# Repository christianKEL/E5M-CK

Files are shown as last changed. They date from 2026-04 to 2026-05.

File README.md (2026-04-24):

# E5M-CK

> Files to install a parallel version of **Klipper mainline** on the Creality Ender 5 Max.

The memos in this repository explain how the shipped binary files were compiled.

---

## ⚠️ Beta version

**Do not install it if you have no brain to fix/mod/custom.**
You can do a factory reset by placing a empty file called factory_reset without extension on a FAT32 formated USB Key. Plug the USB key, turn the power on and you will be again on the factory Creality Firmeware.

---

## 🚀 Installation and configurations

# Klipper installation
```bash
wget --no-check-certificate https://raw.githubusercontent.com/christianKEL/E5M-CK/main/install.sh -O /tmp/install.sh && sh /tmp/install.sh
```
# Eddy configuration
```bash
wget --no-check-certificate https://raw.githubusercontent.com/christianKEL/E5M-CK/main/eddy.sh -O /tmp/eddy.sh && sh /tmp/eddy.sh
```

# Switch temporary to Creality Fork to do the Input Shaping and switch back to Klipper Mainline
```bash
wget --no-check-certificate https://raw.githubusercontent.com/christianKEL/E5M-CK/main/switch.sh -O /tmp/switch.sh && sh /tmp/switch.sh
```
---

## ❤️ Support

I've spent dozens of hours on this (my wife can tell...). If you want to buy me a spool of filament, a new hotend, a trip to Sydney or a new car, please donate here:

👉 **[Donate via PayPal](https://www.paypal.com/donate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)**

---

## 🔗 Links

### Documentation and contact

- 🌐 **My website** with more tips on the Ender 5 Max: [e5mdocumentation.kinsta.cloud](https://e5mdocumentation.kinsta.cloud/)
- 📘 **My Facebook profile** if you want to contact me: [Christian Kelhetter](https://www.facebook.com/christian.kelhetter)
  > Do not send me crap or ask me stupid questions → you will be banned.
- 👥 **Ender 5 Max community on Facebook** — I'm active there and other very good people are too: [Ender 5 Max Users Group](https://www.facebook.com/groups/1131970151918848)

### Hardware and 3D models

- 🛒 **Buy the BTT Eddy**: [biqu.equipment](https://biqu.equipment/products/bigtreetech-eddy)
- 🖨️ **Nebula horizontal holder for GuppyScreen**: [Creality Cloud](https://www.crealitycloud.com/model-folder/8294565794?id=69bd23091a225a24eaf224de&type=1)
- 🖨️ **Eddy mount (beta) used in this project**: [Creality Cloud](https://www.crealitycloud.com/model-folder/8294565794?id=69bd23091a225a24eaf224de&type=1)

---

## 🙏 Thanks to

- **[Guilouz](https://github.com/Guilouz)** for his [Creality Helper Script](https://github.com/Guilouz/Creality-Helper-Script-Wiki)
- **GitHub** for hosting everything and providing free Codespaces
- **[CoPrint](https://github.com/coprint)** because their project showed me the way
- **[Kevin O'Connor](https://ko-fi.com/koconnor)** for Klipper itself

---

## 🖕 CR\*ALITY S\*CKS

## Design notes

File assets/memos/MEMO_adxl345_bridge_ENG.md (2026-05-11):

# TECHNICAL MEMO — ADXL345 Bridge

## Klipper mainline + Creality nozzle MCU 2023 firmware

**Author:** Christian KELHETTER
**Project:** E5M-CK — https://github.com/christianKEL/E5M-CK
**Date:** May 2026

---

## 1. Context and problem statement

### 1.1 The hardware

The Ender 5 Max printer ships with two MCUs:

- **Mainboard MCU** (`mcu`): Creality CR4NS200323C10, GD32F303RET6, on `/dev/ttyS1`. Runs Klipper-compatible firmware that has been successfully ported to mainline.
- **Nozzle MCU** (`nozzle_mcu`): Creality CR-NOZZLE_V21, GD32F303CBT6, on `/dev/ttyS7`. Runs a **Creality 2023 firmware build** (`341a2c18-dirty-20230717_152940-cxsw`). This firmware drives the hotend heater, the part fans, the filament sensor, and **the embedded ADXL345 accelerometer**.

The nozzle MCU firmware is **not flashable** through the standard Klipper mainline `make flash` workflow without significant rework: the bootloader signature, build environment, and pin map are Creality-specific. Replacing it would be possible but risky — the nozzle MCU controls the heater, and a bad flash bricks the toolhead.

**Therefore the nozzle MCU must keep running its 2023 Creality firmware** while the rest of the system runs Klipper mainline 2026.

### 1.2 The protocol mismatch

When Klipper mainline 2026 talks to the nozzle MCU, low-level commands like motor steps and heater PWM work fine: those signatures haven't changed in years. However, the **ADXL345 sensor protocol** has diverged significantly between the Creality 2023 fork and Klipper mainline.

Symptoms when trying to use a stock `[adxl345]` config block with the Creality nozzle MCU:

```
Got error -1 in adxl345 query_status: cmd query_adxl345 unknown
```

or:

```
Unknown adxl345_data sequence
```

Klipper mainline issues a different `query_adxl345` command than what the 2023 firmware understands, and parses the bulk data response differently.

### 1.3 What `accel_chip_proxy` is

The Creality fork of Klipper ships a custom Python module called `accel_chip_proxy.py` (in `/usr/share/klipper/klippy/extras/`). This module is the glue between the Creality `[accel_chip_proxy]` config section and the Creality firmware ADXL345 driver. It does:

1. Listens for the legacy Creality `klippy:mcu_identified` event.
2. When that event fires, dynamically constructs an ADXL345 chip object using the Creality fork's `ADXL345Creality` class (also custom).
3. Registers the chip as an accelerometer and exposes the standard accelerometer API (`start_internal_client`, `read_reg`, `set_reg`, `last_query_time`).

When the user installs Klipper mainline (which has its own, modern `adxl345.py` and no `accel_chip_proxy` whatsoever), `[accel_chip_proxy]` configs become unrecognized and ADXL345 functionality is lost.

---

## 2. Investigation — what differs between Creality 2023 and Klipper mainline

This is the most useful part of the memo: the precise wire-level differences. Knowing them is what made the bridge possible.

### 2.1 `query_adxl345` command signature

**Creality 2023 firmware (`/usr/data/klipper/src/sensor_adxl345.c`):**

```c
DECL_COMMAND(command_query_adxl345,
             "query_adxl345 oid=%c clock=%u rest_ticks=%u");
```

Three parameters: `oid`, `clock`, `rest_ticks`.

**Klipper mainline:**

```c
DECL_COMMAND(command_query_adxl345,
             "query_adxl345 oid=%c rest_ticks=%u");
```

Two parameters: `oid`, `rest_ticks`. The `clock` parameter has been removed.

A mainline `[adxl345]` driver issuing the 2-parameter form is rejected by the Creality firmware as "unknown command".

### 2.2 `adxl345_data` response format

**Creality 2023 firmware** sends bulk samples packed **5 bytes per sample**:

- Each batch: `oid(1) + sequence(2) + samples(N×5)`
- Sample bit-packing (per `_extract_samples` in the Creality `adxl345.py`):

```python
xlow  = msg[0]
ylow  = msg[2]
zlow  = msg[4]
xzhigh = msg[6]
xhigh  = (msg[1] & 0x1f) | ((xzhigh & 0xe0) << 0)
yhigh  = (msg[3] & 0x1f) | ((xzhigh << 5) & 0xe0)
zhigh  = (msg[5] & 0x1f) | ((xzhigh << 2) & 0x60)   # 2 bits only
```

**Critical:** `zhigh` only takes **2 bits** from `xzhigh`, masked with `0x60`, NOT `0xe0`. This is non-obvious. If you assume symmetry with X and Y and apply `0xe0`, the Z axis values are wrong.

**Klipper mainline** uses a different layout (FixedFreqReader + BatchBulkHelper, 6 bytes per sample, no bit-packing). It can't decode the Creality format and vice versa.

### 2.3 API hooks

**Creality 2023 fork:** uses an `klippy:mcu_identified` event that fires once per MCU. This is custom — not present in mainline.

**Klipper mainline:** uses `register_config_callback()` on the MCU object, fired during config parsing. Different timing, different signature.

**Implication:** any code that hooks into `klippy:mcu_identified` (such as the original `accel_chip_proxy.py`) silently does nothing on mainline. The chip is never instantiated.

### 2.4 `mcu.register_response` location

**Creality 2023 fork:** `mcu.register_response(...)` directly on the MCU object.

**Klipper mainline 2026:** `mcu._serial.register_response(...)`. The method moved one level deeper as part of an internal refactor.

A direct copy of the Creality `ADXL345Creality` class will fail with:

```
AttributeError: 'MCU' object has no attribute 'register_response'
```

at the moment it tries to register its bulk data callback.

### 2.5 SPI — software bus

Creality 2023 uses a software SPI implementation (bit-banging on GPIOs). The pins on the Ender 5 Max nozzle MCU are:

- `cs_pin = nozzle_mcu:PA4`
- `clock_pin = nozzle_mcu:PA5`
- `mosi_pin = nozzle_mcu:PA7`
- `miso_pin = nozzle_mcu:PA6`
- `spi_speed = 5000000`

The Klipper mainline `[adxl345]` driver will refuse software SPI on Creality firmware because the MCU command name has changed (`config_software_spi` → `spi_set_software_bus` deprecation warning, but functional). The code path through the bridge has to call the firmware command Creality understands.

### 2.6 Sample rate ceiling

Klipper mainline default is `rate: 3200 Hz`. The Creality 2023 firmware MCU **cannot sustain 3200 Hz** during a TEST_RESONANCES sweep — the host scheduler reports `Stepper too far in past` because the bulk data flood saturates the UART link.

**Empirically determined ceiling: `adxl345_rate: 1600`.** At 1600 Hz, the link is stable and TEST_RESONANCES completes cleanly. SHAPER_CALIBRATE works at 1600 Hz with no measurable accuracy loss.

---

## 3. Solution — the bridge

### 3.1 Design

Two Python files, dropped into `klippy/extras/`:

1. **`adxl345_creality.py`** (~415 lines): a port of the Creality `ADXL345` class.
   - Reuses Klipper mainline `AccelCommandHelper` and `AccelQueryHelper` (no need to reinvent the standard accelerometer machinery).
   - Keeps the **hardware logic intact** from Creality: software SPI handshake, ClockSyncRegression, `_extract_samples` with the correct `0x60` mask for Z high bits.
   - Replaces the **transport layer** with `bulk_sensor.BatchBulkHelper`, which is the modern equivalent of the deprecated `motion_report.APIDumpHelper`.
   - Uses `mcu._serial.register_response(...)` for the data callback (the new location).
   - Provides two classes: `ADXL345Creality` and `LIS2DWCreality`. Both default to `register_commands=False`, so they don't conflict with potential mainline `[adxl345]` registration.

2. **`accel_chip_proxy.py`** (~120 lines): a **drop-in replacement** for the Creality stock proxy.
   - Same `[accel_chip_proxy]` config section name — slicer scripts and existing `printer.cfg` blocks don't need changes.
   - Instantiates `ADXL345Creality` directly during `__init__` (no event handler — it just runs immediately at config load).
   - Exposes the accelerometer API by direct delegation: `start_internal_client`, `read_reg`, `set_reg`, `last_query_time`.
   - Provides a small `_ConfigWrapperProxy` that re-prefixes options (`cs_pin` → `adxl345_cs_pin`) so the existing Creality config style is preserved without breaking the underlying ADXL345Creality class.

### 3.2 Why two files

Single-file approaches were tried first but ran into config-parsing collisions: the moment the proxy registered a chip with the same name, Klipper mainline complained `Accelerometer with name 'X' already defined`. The two-file split lets the inner ADXL345 class register without naming conflict (`register_commands=False`), and the outer proxy presents the stable name to the rest of Klipper.

### 3.3 Configuration block (in `printer.cfg`)

```ini
[accel_chip_proxy]
accel_use_chip: adxl345
adxl345_cs_pin: nozzle_mcu:PA4
adxl345_spi_speed: 5000000
adxl345_spi_software_sclk_pin: nozzle_mcu:PA5
adxl345_spi_software_mosi_pin: nozzle_mcu:PA7
adxl345_spi_software_miso_pin: nozzle_mcu:PA6
adxl345_axes_map: x,-z,y
adxl345_rate: 1600

# Same block duplicated for lis2dw if present (omitted here).

[resonance_tester]
accel_chip: accel_chip_proxy
probe_points: 200, 200, 10
accel_per_hz: 50
```

**Notes:**

- `axes_map: x,-z,y` is specific to the Ender 5 Max accelerometer mounting orientation. Other printers will have different maps.
- `accel_per_hz: 50` (lower than the 75 default) reduces excitation amplitude. Helpful on a heavy Ender 5 Max gantry.

### 3.4 Acceptable raw-output anomaly

When idle, the bridge reports static gravity vectors that are **wrong in absolute terms**:

```
ACCELEROMETER_QUERY
Recv: // accel_chip_proxy values: x=-32700 y=-11360 z=-9230 (magnitude 3.66g)
```

Expected magnitude at rest = 1.000g. Observed = 3.66g. The cause is unclear (possibly a sign-extension bug in the Creality 5-byte unpacking that we didn't fix because it doesn't matter for our use case).

**This is acceptable.** SHAPER_CALIBRATE and TEST_RESONANCES operate on the **dynamics** (deltas), not the absolute values. The frequency response curves are correct, the recommended shapers match a manual calibration, and the printed parts confirm.

---

## 4. Expected warnings — and the Klipper-side suppression patch

The bridge works by talking to the Creality 2023 firmware using its **original protocol**. Klipper mainline 2026 expects newer command names for some features. When the MCU doesn't advertise them, Klipper emits a deprecated-feature warning on every startup. Since we **deliberately** keep the Creality firmware (cf §1.1), reflashing isn't an option — the warnings would be permanent visual noise in Fluidd.

### 4.1 Warnings observed

After bridge installation, Klipper emits warnings of this form:

```
MCU 'nozzle_mcu' has deprecated code (it is missing feature 'spi_set_sw_bus').
Recompiling and flashing is recommended (MCU version '341a2c18-dirty-20230717_152940-cxsw-virtual-machine',
host version 'v0.13.0-642-g1b1da9331-dirty').
```

And similarly for `STEPPER_STEP_BOTH_EDGE`.

Both are **functionally harmless** but visually persistent. Detail per feature:

#### `spi_set_sw_bus`

Generated by `klippy/extras/bus.py:97`:

```python
if self.mcu.try_lookup_command("spi_set_sw_bus oid=%c miso_pin=%u mosi_pin=%u "
                               "sclk_pin=%u mode=%u pulse_ticks=%u"):
    # use the command
else:
    configfile.deprecate_mcu_code(self.mcu, 'spi_set_sw_bus')
    # fall back to old form (still works)
```

The Creality 2023 firmware **does** have a `spi_set_sw_bus` command, but with a slightly different parameter signature (probably without `pulse_ticks` or with different parameter ordering). `try_lookup_command` fails to match the modern signature, so the warning fires. The fall-back code path then uses the older signature successfully.

This is precisely the path the ADXL345 bridge needs: any rewrite to use `config_software_spi` would require reflashing the nozzle MCU, which we explicitly avoid.

#### `STEPPER_STEP_BOTH_EDGE`

A different deprecation related to step pulse handling. The Creality firmware doesn't support both-edge stepping; we compensate with `step_pulse_duration: 0.000000501` in every `[stepper_*]` block. The behavior is identical to both-edge stepping but uses two pulses per step instead of one.

### 4.2 Suppression patch

Both warnings are suppressed by patching `klippy/configfile.py`:

```python
def deprecate_mcu_code(self, mcu, feature, msg=None):
    # E5M-CK: suppress known deprecated-feature warnings for Creality
    # 2023 firmware which we deliberately keep (cannot reflash nozzle MCU
    # safely — see §1.1).
    #   STEPPER_STEP_BOTH_EDGE: compensated by step_pulse_duration in cfg
    #   spi_set_sw_bus: legacy software-SPI command name (still functional)
    E5M_CK_SUPPRESSED_FEATURES = (
        'STEPPER_STEP_BOTH_EDGE',
        'spi_set_sw_bus',
    )
    if feature in E5M_CK_SUPPRESSED_FEATURES:
        return
    mcu_name = mcu.get_name()
    # ... original code continues
```

The early `return` short-circuits the warning generation. Other deprecation warnings (for features we don't know about and might genuinely care about) are still emitted normally.

### 4.3 Why not just ignore the warning visually?

Three reasons we patch rather than ignore:

1. **A persistent red banner in Fluidd hides real warnings.** If a future genuine deprecation appears, we want to see it.
2. **Documentation discipline.** A user (or future-me) looking at the printer should see "zero warnings" as the normal state, not "two warnings, both intentional".
3. **The cost is trivial.** A 5-line patch to one file, easy to re-apply after Klipper updates.

### 4.4 Maintenance after Klipper update

Klipper updates may overwrite `configfile.py`. The backup is preserved as `configfile.py.bak.before_e5m_ck` (and `.bak.before_spi_warning.<timestamp>` for the most recent revision). To re-apply after an update:

```bash
# Compare current vs known-patched state
diff /usr/data/klipper/klippy/configfile.py \
     /usr/data/klipper/klippy/configfile.py.bak.before_e5m_ck

# If the patch is missing, re-apply (use the Python script in installs/
# or run sed/manual edit on the deprecate_mcu_code function)
```

A future enhancement to `install_adxl_patch_v2.sh` could detect a missing patch and offer to re-apply it.

---

## 5. Installer — `install_adxl_patch_v2.sh`

### 4.1 Distribution model

Installer hosted on GitHub Raw to enable one-line install on the printer:

```sh
sh -c "$(wget --no-check-certificate -qO - \
  https://raw.githubusercontent.com/christianKEL/E5M-CK/main/installs/install_adxl_patch_v2.sh)" \
  install
```

The two `.py` files are also fetched from raw.githubusercontent during install.

### 4.2 Subcommands

- `install` — fresh install (idempotent — won't break a system that's already patched).
- `update` — fetch latest `.py` files and reinstall.
- `uninstall` — restore from backup.
- `status` — report what's currently installed.
- `help` — usage.

### 4.3 What it does

1. Verifies prerequisites: Klipper mainline path (`/usr/data/klipper/klippy/extras`), Python version, write permissions.
2. Downloads `adxl345_creality.py` and `accel_chip_proxy.py` from GitHub Raw to `/tmp`.
3. Validates each file with `python -m py_compile` (catches transport corruption).
4. Backs up `printer.cfg` to `printer.cfg.bak.adxl345-creality`.
5. Detects whether the bridge config block is already present (markers `# >>> adxl345-creality-bridge >>>` / `# <<< ... <<<`).
6. **Inserts the bridge block in `printer.cfg`** (this is the tricky part — see 4.4).
7. Copies the `.py` files to `/usr/data/klipper/klippy/extras/`.
8. Optionally restarts Klipper.

### 4.4 The `printer.cfg` insertion bug — and the fix

**Initial bug:** the installer appended the bridge block at the **end** of `printer.cfg`. This put the block **after** the auto-generated `#*# SAVE_CONFIG` section. Klipper rejected the file at restart with:

```
Section 'accel_chip_proxy' not in '#*#' SAVE_CONFIG marker; or possibly malformed file
```

**Fix:** detect the start of the SAVE_CONFIG block and insert **before** it.

```sh
# Find first line starting with '#*#' (SAVE_CONFIG block start)
SAVE_CONFIG_LINE=$(grep -n '^#\*#' "$PRINTER_CFG" | head -1 | cut -d: -f1)

if [ -n "$SAVE_CONFIG_LINE" ]; then
    # Insert before line $SAVE_CONFIG_LINE
    head -n $((SAVE_CONFIG_LINE - 1)) "$PRINTER_CFG" > "$PRINTER_CFG.tmp"
    cat "$BRIDGE_BLOCK" >> "$PRINTER_CFG.tmp"
    tail -n +$SAVE_CONFIG_LINE "$PRINTER_CFG" >> "$PRINTER_CFG.tmp"
    mv "$PRINTER_CFG.tmp" "$PRINTER_CFG"
else
    # No SAVE_CONFIG block yet — safe to append
    cat "$BRIDGE_BLOCK" >> "$PRINTER_CFG"
fi
```

This is the same trick a Klipper SAVE_CONFIG uses internally. The block markers (`# >>> adxl345-creality-bridge >>>`) are left in place so future runs of the installer can detect "already installed" and skip.

---

## 6. Validation procedure

### 5.1 Health check

```bash
# Klipper started cleanly?
curl -s http://localhost:7125/printer/info | \
  python3 -c "import sys,json; print(json.load(sys.stdin)['result']['state'])"
# Expected: ready

# Chip is registered?
echo "ACCELEROMETER_QUERY" | <send via Fluidd console>
# Expected: live X/Y/Z values (any magnitude — see §3.4)

# Noise floor?
echo "MEASURE_AXES_NOISE" | <send via Fluidd console>
# Expected: noise values in 1-100 range; > 1000 indicates a real issue
```

### 5.2 Calibration test

```
SHAPER_CALIBRATE
```

Successful output ends with something like:

```
Recommended shaper_type_x = mzv, shaper_freq_x = 50.8 Hz
Recommended shaper_type_y = mzv, shaper_freq_y = 40.0 Hz
```

Apply via:

```ini
[input_shaper]
shaper_type_x: mzv
shaper_freq_x: 50.8
shaper_type_y: mzv
shaper_freq_y: 40.0
```

Then `SAVE_CONFIG` (or edit by hand and `FIRMWARE_RESTART`).

### 5.3 Belt test (CoreXY only)

```
TEST_RESONANCES AXIS=1,1 OUTPUT=raw_data
TEST_RESONANCES AXIS=1,-1 OUTPUT=raw_data
```

Generates two CSVs in `/tmp`. Used by the GuppyScreen Belts function — see the separate `MEMO_guppyscreen_belts_ENG.md`.

---

## 7. Failure modes encountered (and resolved)

The route to a working bridge passed through several failures. Documenting them avoids repeating them.

| Symptom | Root cause | Fix |
|---|---|---|
| `'accel_chip_proxy' is not an accelerometer` | Proxy didn't expose `start_internal_client` | Added direct delegation methods |
| `Accelerometer with name 'accel_chip_proxy' already defined` | Inner chip was registering with the same name as outer proxy | Added `register_commands=False` flag on inner chip |
| `MCU already configured` | Inner chip instantiated too early (during another callback) | Moved instantiation to `__init__` of the proxy via `register_config_callback` |
| `'MCU' object has no attribute 'register_response'` | API moved in mainline | Use `mcu._serial.register_response` |
| `Stepper too far in past` during TEST_RESONANCES | UART link saturation at 3200 Hz | Set `adxl345_rate: 1600` |
| `Section 'accel_chip_proxy' not in '#*#' SAVE_CONFIG marker` | Installer appended config to end of file, after SAVE_CONFIG | Insert before SAVE_CONFIG line |
| Z values wildly wrong | Wrong mask `0xe0` instead of `0x60` for Z high bits | Apply correct mask in `_extract_samples` |

---

## 8. Limits of the bridge

### 7.1 What works

- `ACCELEROMETER_QUERY` (returns values, magnitudes wrong but readable)
- `MEASURE_AXES_NOISE`
- `TEST_RESONANCES AXIS=X|Y|Z`
- `TEST_RESONANCES AXIS=1,1` and `AXIS=1,-1` (CoreXY belt tests)
- `SHAPER_CALIBRATE`
- `ACCELEROMETER_MEASURE` (raw data dump)

### 7.2 What doesn't work

- Absolute gravity-vector measurements (see §3.4) — not used by anything important
- Fast scan modes (resonance auto-tuning at maximum frequencies) — limited by `adxl345_rate: 1600`

### 7.3 Failure modes that would require a re-port

- Future Klipper mainline refactor of `bulk_sensor.BatchBulkHelper` API
- Creality firmware update to the nozzle MCU (would change wire format again)

The bridge is therefore a **frozen-in-time** solution. It's tied to:

- Klipper mainline ~v0.13.0-628 (and presumably nearby commits — the `bulk_sensor` API stable around this point)
- Creality nozzle firmware `341a2c18-dirty-20230717_152940-cxsw`

If either side moves significantly, the bridge needs to be re-tested and possibly re-ported.

---

## 9. Repository layout

```
E5M-CK/
├── files/
│   ├── adxl345_creality.py
│   └── accel_chip_proxy.py
├── installs/
│   └── install_adxl_patch_v2.sh
└── docs/
    ├── MEMO_c_helper_ENG.md
    └── MEMO_adxl345_bridge_ENG.md   ← this file
```

URLs (raw):

- `https://raw.githubusercontent.com/christianKEL/E5M-CK/main/files/adxl345_creality.py`
- `https://raw.githubusercontent.com/christianKEL/E5M-CK/main/files/accel_chip_proxy.py`
- `https://raw.githubusercontent.com/christianKEL/E5M-CK/main/installs/install_adxl_patch_v2.sh`

---

## 10. Recap — minimum commands

### 9.1 Install on a fresh system

```bash
sh -c "$(wget --no-check-certificate -qO - \
  https://raw.githubusercontent.com/christianKEL/E5M-CK/main/installs/install_adxl_patch_v2.sh)" \
  install

/etc/init.d/S55klipper_service restart
```

### 9.2 Uninstall

```bash
sh -c "$(wget --no-check-certificate -qO - \
  https://raw.githubusercontent.com/christianKEL/E5M-CK/main/installs/install_adxl_patch_v2.sh)" \
  uninstall

/etc/init.d/S55klipper_service restart
```

### 9.3 Validate

```bash
curl -s http://localhost:7125/printer/info | \
  python3 -c "import sys,json; print(json.load(sys.stdin)['result']['state'])"
# Expected: ready
```

Then from Fluidd console:

```
ACCELEROMETER_QUERY
SHAPER_CALIBRATE
```

---

*Document written in May 2026 as part of the E5M-CK project. Companion to `MEMO_c_helper_ENG.md` and `MEMO_guppyscreen_belts_ENG.md`.*

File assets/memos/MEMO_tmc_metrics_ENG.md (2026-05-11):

# TECHNICAL MEMO — GuppyScreen TMC Metrics

## Klipper mainline + Creality 2023 nozzle MCU + TMC2209 drivers

**Author:** Christian KELHETTER
**Project:** E5M-CK — https://github.com/christianKEL/E5M-CK
**Date:** May 2026
**Status:** **Disabled — not viable on this stack** (see §6 for rationale)

---

## 1. Context and purpose

### 1.1 What TMC Metrics is

GuppyScreen ships a touch UI panel called **TMC Metrics** (binary string `Shake Belts` / `Input Shaper` / **`TMC Metrics`**) that displays per-driver Trinamic status in real time: motor current (`i_rms`), chopper mode (SpreadCycle/StealthChop), thermal flags (`otpw`, `ot`), stallguard value, and so on. It's a diagnostic tool — equivalent to Klipper's `DUMP_TMC` command but always-on and graphical.

The on-screen warning in the binary explicitly notes:

```
TMC Metrics is experimental and disabled by default.
Turn it on as needed. For in-depth detail, refer to the TMC driver datasheet.
```

That's the upstream-acknowledged hint that this feature is **fragile**.

### 1.2 The data path

```
GuppyScreen UI (TmcStatusPanel)
    ↓ webhooks subscribe "tmcstatus"
Moonraker (klippy_connection)
    ↓ objects/subscribe { "tmcstatus": null }
Klipper webhooks (_do_query)
    ↓ poll get_status(eventtime) ~10 Hz
tmcstatus.py (TMCStatus.get_status)
    ↓ for each driver:
    ↓   tmcobj.mcu_tmc.get_register('DRV_STATUS')   ← TMC UART read
    ↓   tmcobj.mcu_tmc.get_register('SG_RESULT')    ← TMC UART read
    ↓   tmcobj.fields.get_field(...) × ~15 fields   ← cached reads
tmc_uart.py (mcu_uart.reg_read)
    ↓ tmcuart_send_cmd.send([oid, msg, 10])
nozzle MCU (CR-NOZZLE_V21, Creality 2023 firmware)
    ↓ executes tmcuart_send / tmcuart_response
TMC2209 driver
    → returns register value
```

For 4 drivers (`stepper_x`, `stepper_y`, `stepper_z`, `extruder`), each `get_status` call performs roughly:

- 4 × `DRV_STATUS` reads (UART round-trip)
- 4 × `SG_RESULT` reads (UART round-trip)
- ~60 cached field reads (no UART, but Python overhead)

= **8 UART transactions per poll**, polled at ~10 Hz → **~80 UART round-trips per second**, shared with all other Klipper traffic (heaters, accelerometer, motion commands).

### 1.3 The wiring on the E5M-CK

```ini
[tmc2209 stepper_x]   # mainboard MCU UART
[tmc2209 stepper_y]   # mainboard MCU UART
[tmc2209 stepper_z]   # mainboard MCU UART
[tmc2209 extruder]    # nozzle_mcu UART (Creality 2023 firmware!)
```

The extruder TMC is on the **nozzle MCU**, which runs the legacy Creality 2023 firmware (`341a2c18-dirty-20230717_152940-cxsw`). This firmware has been observed in this project to have **stricter watchdog/timeout behavior** than mainline Klipper firmware (cf the ADXL345 bridge work in `MEMO_adxl345_bridge_ENG.md`).

---

## 2. The starting state — module already present

The `tmcstatus.py` module ships as part of the GuppyScreen install:

```
/usr/data/guppyscreen/k1_mods/tmcstatus.py
```

and is symlinked into Klipper's extras directory:

```
/usr/data/klipper/klippy/extras/tmcstatus.py
  → /usr/data/guppyscreen/k1_mods/tmcstatus.py
```

The companion module loader `guppy_module_loader.py` registers two G-code commands:

```python
_GUPPY_LOAD_MODULE SECTION=tmcstatus
_GUPPY_UNLOAD_MODULE SECTION=tmcstatus
```

These are designed for **lazy loading**: GuppyScreen calls `_GUPPY_LOAD_MODULE` when the user opens the TMC Metrics panel, and `_GUPPY_UNLOAD_MODULE` when they leave. The idea is to avoid the UART load when no one is looking.

The mechanism works via `printer.load_object()` / `printer.objects.pop()`.

---

## 3. Initial diagnosis — module not loaded

A query before any change:

```bash
$ curl -s 'http://localhost:7125/printer/objects/query?tmcstatus'
{"result":{"eventtime":233.171192666,"status":{"tmcstatus":{}}}}
```

The object exists in Moonraker's subscription list (because GuppyScreen subscribes to it on connect) but is **empty**: there's no `[tmcstatus]` section in `printer.cfg`, so the Python module is never instantiated. GuppyScreen's TMC Metrics panel displays empty fields.

That's how the system has been running historically — silently broken, no crash, no functionality.

---

## 4. Activation attempts and observed failures

Three increasingly sophisticated patches were attempted. All three failed, in increasingly informative ways.

### 4.1 Attempt 1 — declare `[tmcstatus]` in config

The first try: add a `[tmcstatus]` section in a new file `tmcstatus.cfg` included from `printer.cfg`:

```ini
[include tmcstatus.cfg]   # line 17 of printer.cfg
```

```ini
# tmcstatus.cfg
[tmcstatus]
```

Result on FIRMWARE_RESTART:

```
Unknown config object 'tmc2209 stepper_x'
Once the underlying issue is corrected, use the "RESTART"
command to reload the config and restart the host software.
Printer is halted
```

**Root cause**: Klipper processes config sections **in their order of appearance** after `[include]` expansion. With `[include tmcstatus.cfg]` at line 17 and `[tmc2209 stepper_x]` at line 87+, the module's `__init__` runs **before** the TMC drivers are instantiated. The direct call `self.handle_connect()` in `__init__` then fails:

```python
def __init__(self, config):
    ...
    for driver in TRINAMIC_DRIVERS:
        self.configured_steppers.extend(
            [n.get_name() for n in self.config.get_prefix_sections(driver)])
    self.handle_connect()   # ← too early

def handle_connect(self):
    for s in self.configured_steppers:
        tmc = self.printer.lookup_object(s)   # → "Unknown config object"
```

### 4.2 Attempt 2 — defer to `klippy:connect`

Standard Klipper idiom: register an event handler for `klippy:connect`, which fires **after** all sections have been instantiated.

```python
# Patch
self.printer.register_event_handler("klippy:connect", self.handle_connect)
```

Result on FIRMWARE_RESTART:

```
File "tmcstatus.py", line 19, in __init__
File "tmcstatus.py", line 23, in handle_connect
  self.printer.register_event_handler("klippy:connect", ...)
File "klippy.py", line 79, in lookup_object
  raise self.config_error("Unknown config object '%s'" % (name,))
configparser.Error: Unknown config object 'tmc2209 stepper_x'
```

**Root cause**: the traceback is deceptive. The handler **was** registered, but Klipper called it **immediately** because the `klippy:connect` event had already fired by the time `[tmcstatus]` (loaded as last config section) finished its `__init__`. When Klipper sees a handler registered for an event that has already happened, it dispatches it synchronously. The handler then runs in the same context as `__init__`, before TMC drivers exist.

### 4.3 Attempt 3 — force-load TMC sections from `handle_connect`

If `lookup_object` fails, try `load_object` to force creation of the section:

```python
def handle_connect(self):
    for s in self.configured_steppers:
        tmc = self.printer.lookup_object(s, None)
        if tmc is None:
            try:
                tmc = self.printer.load_object(self.config, s)
            except Exception as e:
                logging.info("tmcstatus: failed to load %s: %s", s, e)
                continue
        self.tmcs[s] = tmc
```

Result on FIRMWARE_RESTART: Klipper started cleanly. The `[tmcstatus]` module loaded, populated `self.tmcs` correctly. Then `_GUPPY_LOAD_MODULE` was triggered to enable the lazy-load path. Within 2 seconds:

```
Receive: ... shutdown clock=1325715900 static_string_id=Command request
gcode state: ...
Repeat unhandled exception during run
Traceback (most recent call last):
  File "/usr/data/klipper/klippy/reactor.py", line 153, in update_timer
    if timer_handler.timer_is_running:
AttributeError: 'NoneType' object has no attribute 'timer_is_running'
```

**Root cause**: this is **not** a tmcstatus.py bug. The MCU sent a `shutdown` signal (`Command request` is a Creality 2023 firmware watchdog timeout). During Klipper's shutdown propagation, `reactor.py:153` tried to update a timer that had already been cleared — leading to the `AttributeError` on `timer_is_running`.

The TMC UART polling **triggered the MCU watchdog**. The crash that followed is a separate Klipper mainline bug exposed by the shutdown path, but the root cause is the polling load itself.

### 4.4 Attempt 4 — rate-limit the polling

Added a 1-second cache to `get_status`:

```python
TMC_READ_INTERVAL = 1.0

def get_status(self, eventtime):
    if eventtime - self.last_read_time < TMC_READ_INTERVAL:
        return self.cached_data
    # ... read UART ...
    self.cached_data = data
    self.last_read_time = eventtime
    return data
```

Result: identical crash. The rate-limit doesn't help because the crash happens on the **first** poll after `_GUPPY_LOAD_MODULE`. The polling reduction from ~10 Hz to 1 Hz is moot if the very first read triggers the MCU shutdown.

---

## 5. Root cause analysis

After four attempts, the failure pattern is consistent:

1. The module loads cleanly (with the right deferral).
2. The first TMC UART read triggered by Moonraker's status query causes the nozzle MCU to issue a `shutdown` ("Command request" timeout).
3. During Klipper's shutdown propagation, `reactor.update_timer` is called on an already-cleared timer object, causing `AttributeError`.

Three contributing factors, none of which can be fixed in `tmcstatus.py` alone:

### 5.1 Nozzle MCU firmware (Creality 2023)

The CR-NOZZLE_V21 firmware (`341a2c18-dirty-20230717_152940-cxsw`) has a **strict command-request timeout**. When the Klipper host sends an unexpected `tmcuart_send` command while the MCU is busy with something else (heater control, fan PWM, etc.), the firmware treats it as a protocol violation and shuts down.

This is the same firmware that requires the ADXL345 bridge (`MEMO_adxl345_bridge_ENG.md`) — it's just not designed for the access patterns mainline Klipper expects.

### 5.2 Klipper mainline reactor bug

`reactor.py` line 153:

```python
def update_timer(self, timer_handler, waketime):
    if timer_handler.timer_is_running:
        ...
```

If `timer_handler` is `None` (which happens when a `ReactorCompletion` is cleaned up early during shutdown), this raises `AttributeError`. The proper code would be:

```python
if timer_handler is not None and timer_handler.timer_is_running:
    ...
```

This is a real Klipper bug, present in the version we're running (~v0.13.0-642). Patching it would require either:

- Submitting a PR upstream and waiting for release
- Patching the local copy at every Klipper update

Either way, this only **masks** the crash. The MCU shutdown is still real — it just wouldn't crash Klipper afterward.

### 5.3 Shared UART contention

The TMC drivers share their UART bus with all other Klipper traffic to the same MCU. On the nozzle MCU specifically:

- TMC2209 extruder reg reads (when tmcstatus is active)
- TMC drive current updates
- Heater PWM control commands
- Fan PWM commands
- ADXL345 SPI commands (via the bridge)

The 2023 firmware's UART buffer is small and its command-handling loop strict. Adding a regular flood of TMC reg reads disrupts the timing the firmware expects.

---

## 6. Decision — disable, document, move on

After all four attempts and the root-cause analysis, the conclusion:

**TMC Metrics is not viable on the E5M-CK stack as currently configured.**

The only paths forward are:

| Path | Estimated effort | Risk | Reversible? |
|---|---|---|---|
| Patch Klipper `reactor.py` line 153 | 1 hour | Low | Yes (every update) |
| Fork nozzle MCU firmware to relax watchdog | 8+ hours | **High** (bricks the toolhead heater control) | Hard |
| Move extruder TMC off nozzle MCU | Hardware mod | **High** | No |
| Implement async TMC polling via custom Klipper module | 4 hours | Medium | Yes |
| Accept the limitation | 0 hours | None | N/A |

**Selected path: accept the limitation.** TMC Metrics is informational, not operational. Running prints without it works exactly as before; the GuppyScreen panel simply remains empty.

### 6.1 Final configuration state

```bash
# Module file restored to original (in case of future re-attempt)
$ md5sum /usr/data/guppyscreen/k1_mods/tmcstatus.py
<original md5>

# Include disabled
$ grep tmcstatus /usr/data/printer_data/config/printer.cfg
#[include tmcstatus.cfg]

# Klipper running normally
$ curl -s http://localhost:7125/printer/info | grep state_message
"state_message": "Printer is ready"
```

### 6.2 What works without TMC Metrics

Everything else, completely unaffected:

- Heater control, motion, accelerometer (via ADXL345 bridge), Belts, Input Shaper
- Sensorless homing on X/Y (which uses TMC `diag_pin` directly, no UART polling)
- TMC driver current/sensitivity tuning via `printer.cfg` parameters (no runtime introspection needed)
- Manual one-shot `DUMP_TMC` command (Klipper native, single read, no continuous polling)

If you ever need to inspect TMC state for a specific issue, use `DUMP_TMC STEPPER=stepper_x` from Fluidd console. It performs one read, prints to log, no polling involved.

---

## 7. Future work — paths not pursued

### 7.1 Patch Klipper reactor.py

The cleanest one-line fix to mask the crash:

```python
# /usr/data/klipper/klippy/reactor.py line ~153
def update_timer(self, timer_handler, waketime):
    if timer_handler is not None and timer_handler.timer_is_running:
        ...
```

This wouldn't make TMC Metrics work; it would just prevent Klipper from crashing when the MCU shuts down. The MCU shutdown would still require a `FIRMWARE_RESTART` to recover, so the user experience is "TMC Metrics works for ~2 seconds, then the printer halts and needs restart" — not much improvement.

Worth doing if you're patching `reactor.py` for other reasons anyway. Tag this section for a future revision if such a patch ever happens.

### 7.2 Submit the reactor bug upstream

The bug is real and not E5M-specific. A PR to the Klipper repo with a small test case (any module triggering an MCU shutdown during a webhooks query) would benefit the community. Out of scope for E5M-CK.

### 7.3 Async TMC polling

A custom Klipper module that:

- Reads TMC registers in a **dedicated reactor timer** (not during webhooks `get_status`)
- Schedules reads at a slow, predictable rate (e.g., once per 5 seconds)
- Spaces individual driver reads by 100 ms each to give the MCU breathing room
- Caches values aggressively

Would probably work. Estimated 4 hours of design + coding + testing. The benefit is marginal (a partially-working diagnostic panel) versus the cost. Not done.

### 7.4 Replace nozzle MCU firmware

The 2023 firmware is the strict element. If the firmware were rebuilt from Klipper mainline sources for the GD32F303CBT6 (the chip on CR-NOZZLE_V21), it would presumably tolerate parallel UART reads. But that's the whole "flash a custom firmware to the toolhead MCU" path — high risk, and the project has explicitly chosen to **avoid** that route (cf `MEMO_adxl345_bridge_ENG.md` §1.1).

---

## 8. Recap — minimum commands for reference

If a future maintainer wants to try again, the starting state should be:

```bash
# Verify module is original
md5sum /usr/data/guppyscreen/k1_mods/tmcstatus.py

# Verify Klipper is healthy
curl -s http://localhost:7125/printer/info | python3 -m json.tool | grep state_message
# Expected: "Printer is ready"

# Confirm include is disabled
grep tmcstatus /usr/data/printer_data/config/printer.cfg
# Expected: "#[include tmcstatus.cfg]" (commented)
```

To re-attempt activation (NOT RECOMMENDED without a strategy from §7):

```bash
# Enable
sed -i 's|^#\[include tmcstatus.cfg\]|[include tmcstatus.cfg]|' \
    /usr/data/printer_data/config/printer.cfg

curl -X POST http://localhost:7125/printer/firmware_restart
```

To disable urgently (e.g. if the printer halts on activation):

```bash
sed -i 's|^\[include tmcstatus.cfg\]|#[include tmcstatus.cfg]|' \
    /usr/data/printer_data/config/printer.cfg

/etc/init.d/S55klipper_service restart
```

---

## 9. Repository layout

```
E5M-CK/
├── files/
│   └── (no TMC files — module is upstream, not modified)
├── installs/
│   └── (no TMC installer — feature disabled)
└── docs/
    ├── MEMO_c_helper_ENG.md
    ├── MEMO_adxl345_bridge_ENG.md
    ├── MEMO_guppyscreen_belts_ENG.md
    └── MEMO_tmc_metrics_ENG.md   ← this file
```

The `tmcstatus.cfg` activation file remains in `/usr/data/printer_data/config/` on the printer as a documentation artifact (with its `[tmcstatus]` section), but the `[include]` in `printer.cfg` is commented out.

---

*Document written in May 2026 as part of the E5M-CK project. Companion to `MEMO_c_helper_ENG.md`, `MEMO_adxl345_bridge_ENG.md`, and `MEMO_guppyscreen_belts_ENG.md`.*

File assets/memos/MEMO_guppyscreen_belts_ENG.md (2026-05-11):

# TECHNICAL MEMO — GuppyScreen Belts, Input Shaper & matplotlib

## Klipper mainline + Creality K1-derived stack

**Author:** Christian KELHETTER
**Project:** E5M-CK — https://github.com/christianKEL/E5M-CK
**Date:** May 2026

---

## 1. Context and problem statement

### 1.1 The GuppyScreen Belts feature

GuppyScreen is a touch UI for Klipper, originally developed by ballaswag for Creality K1/K1 Max printers. It runs natively on the printer's display (LVGL-based, no X server needed) and provides shortcuts to common operations.

One of those shortcuts is the **Belts** button: a CoreXY-specific test that measures the resonance response of belt A (X axis path) and belt B (Y axis path) and produces a visual comparison. It's based on Frix-x's `klippain-shaketune` work — same idea, GuppyScreen-integrated.

The expected output:
- A PNG file named `belts_calibration.png`
- Containing a frequency-response chart and a difference spectrogram
- A "similarity score" line at the top (e.g. `Belts estimated similarity: 93.1%`)
- Score above 95% = belts well-balanced; 85-95% = acceptable; below 85% = retension needed.

### 1.2 The toolchain involved

When the user presses the Belts button in GuppyScreen, the following chain executes:

1. GuppyScreen calls `GUPPY_BELTS_SHAPER_CALIBRATION` (a gcode macro defined in `/usr/data/printer_data/config/GuppyScreen/guppy_cmd.cfg`).
2. The macro runs `TEST_RESONANCES AXIS=1,1 OUTPUT=raw_data` and `TEST_RESONANCES AXIS=1,-1 OUTPUT=raw_data` to excite each diagonal direction.
3. Klipper saves two raw CSV files in `/tmp` (one per excitation direction).
4. The macro then runs the **Frix-x graph_belts.py** script (located in `/usr/data/printer_data/config/GuppyScreen/scripts/graph_belts.py`).
5. `graph_belts.py` reads the CSVs, runs PSD analysis using **numpy** + **matplotlib**, and writes `belts_calibration.png` to `/usr/data/printer_data/config/`.
6. GuppyScreen polls the file system, sees the new PNG, and displays it on the touch screen.

### 1.3 The problem on the Ender 5 Max

On the E5M with Klipper mainline 2026 + ADXL345 bridge (see `MEMO_adxl345_bridge_ENG.md`), the **first 4 steps work fine** — TEST_RESONANCES generates valid CSVs. But step 5 (the Frix-x script) crashed in three different ways across iteration:

1. **`Stepper too far in past`** during the test itself — saturation of the UART link at default `adxl345_rate: 3200`. Resolved by setting `adxl345_rate: 1600` in the bridge config.

2. **`terminate called after throwing an instance of 'std::runtime_error'. what(): Couldn't close file. Aborted`** — happened the moment matplotlib tried to load fonts. This is the bug that consumed the most investigation time. See §3.

3. **`FileNotFoundError: '/tmp/raw_data_axis=1.000,-1.000_a.csv'`** — file path mismatch between what the macro expects and what Klipper mainline actually generates. See §4.

This memo documents how each of those was resolved.

---

## 2. The Klipper mainline / Klipper Creality / matplotlib version mismatch

Some context that helps everything else make sense.

### 2.1 The Klipper venv

```bash
$ ls -la /usr/share/klippy-env/
drwxr-xr-x  bin   ...
drwxr-xr-x  lib   ...

$ /usr/share/klippy-env/bin/python --version
Python 3.8.2
```

Created **November 2022** (factory default Creality firmware), Python 3.8.2 (sysrelease 2020).

### 2.2 The packages frozen in there

```
matplotlib  2.2.3   # 2017
numpy       1.16.4  # 2019
Pillow      7.0.0   # 2020
kiwisolver  1.1.0   # ~2018
```

These are **not** required by Klipper itself. The `klippy-requirements.txt` file shipped with Klipper mainline lists only `greenlet`, `cffi`, `Jinja2`, `pyserial`, `python-can`. Numpy and matplotlib are present **only because Creality pre-installed them** for the original belt test scripts.

### 2.3 The libfreetype upgrade

Meanwhile, on the same printer:

```bash
$ /opt/lib/libfreetype.so.6 -> libfreetype.so.6.20.2  (Entware, March 2026)
```

`/opt/` is Entware, an alternative package manager that the user has installed for general MIPS-compatible binaries. Entware's libfreetype is **freetype 2.13.x**.

### 2.4 The ABI conflict

matplotlib 2.2.3 ships with a precompiled C extension:

```
/usr/lib/python3.8/site-packages/matplotlib/ft2font.cpython-38-mipsel-linux-gnu.so
```

This `.so` was compiled in 2017-2018 and **statically linked against the freetype headers of that era** (FT 2.6 / 2.7 / 2.8). When loaded at runtime, it dynamically resolves against the system's `libfreetype.so.6` — but on the E5M with Entware, that's **freetype 2.13**, which has different internal struct sizes, different stream-handling logic, and different memory layout assumptions.

The result: the C++ runtime in `ft2font.so` calls into freetype with what it thinks is a valid `FT_Stream`, freetype writes outside the buffer matplotlib allocated, and on stream cleanup the stack throws:

```
terminate called after throwing an instance of 'std::runtime_error'
  what():  Couldn't close file
```

This crash happens during `matplotlib.font_manager` initialization, which iterates every `.ttf` file in `/usr/lib/python3.8/site-packages/matplotlib/mpl-data/fonts/ttf/`. Even on a single bad font, the C++ exception propagates up and aborts the Python interpreter.

---

## 3. Investigation of the matplotlib font crash

This is the section that documents all the things that **didn't work**, before we found the answer. Useful reading because the same dead-ends will tempt future contributors.

### 3.1 What we ruled out

#### Disabling individual fonts

Hypothesis: maybe one specific font file is corrupted and crashes freetype. Approach: disable fonts one by one, see which one stops the crash.

```bash
# Iteration 1: rename all STIX fonts (math fonts, often weird)
mv STIX*.ttf STIX*.ttf.disabled
# → still crashes, this time on DejaVuSerifDisplay.ttf

# Iteration 2: disable DejaVuSerifDisplay too
# → still crashes, this time on cm10.ttf (Computer Modern)

# Iteration 3: disable all Computer Modern + Display fonts
# → still crashes, this time on DejaVuSerif-Bold.ttf
```

Pattern: every iteration, the next font in the alphabetical scan crashes. This is **not a bad-font issue** — it's a **systemic ABI issue** that affects every font.

#### The "keep only DejaVuSans" approach

Hypothesis: maybe matplotlib only really needs DejaVuSans. Keep that one, disable everything else.

```bash
for f in *.ttf; do
    case "$f" in
        DejaVuSans.ttf|DejaVuSans-Bold.ttf|DejaVuSans-Oblique.ttf|DejaVuSans-BoldOblique.ttf) ;;
        *) mv "$f" "${f}.disabled" ;;
    esac
done

# Test:
/usr/share/klippy-env/bin/python -c "import matplotlib; matplotlib.use('Agg'); import matplotlib.pyplot"
# → "Couldn't close file. Aborted"
```

Even on DejaVuSans alone, freetype 2.13 + matplotlib 2.2.3's `ft2font.so` crashes. Confirmed: it's not the font, it's the ABI.

### 3.2 Backend hint: `matplotlib.use('Agg')` — does it help?

Hypothesis: maybe a non-default backend avoids loading display-related fonts.

```python
import matplotlib
matplotlib.use('Agg')          # before pyplot import — allegedly safe
import matplotlib.pyplot       # → still crashes
```

No difference. The crash is during `font_manager` initialization, which `pyplot` triggers regardless of backend.

### 3.3 Compiling matplotlib from source — paths considered

#### Path A: native build on the printer

The MIPS CPU has 2 cores. Compiling matplotlib 3.5+ takes ~30-90 minutes natively. Disk space:

```
$ df -h /
Filesystem      Size      Used Available Use%
overlayfs:/     290.5M    214.4M     61.1M  78%
```

Tight. Not impossible if `TMPDIR` is redirected to `/usr/data` (which has 4.9 GB free), but several deps need C compilation: `Cython`, `kiwisolver`, `contourpy`. Each of those wants headers we don't have (no `python3-dev` package in Entware by default for some of them).

Tried — pip install of `matplotlib<3.6` from PyPI on the printer with full env redirection. Failed at the `freetype.h` header link step (Entware ships the lib but not the dev headers). Moot anyway because of path B.

#### Path B: cross-compile in GitHub Codespaces

Already done for `c_helper.so` (see `MEMO_c_helper_ENG.md`). The toolchain is:

- Ingenic GCC 5.2 from `Dafang-Hacks/mips-gcc520-glibc222-64bit-r3.2.1`
- Target flags: `-mnan=2008 -mfp64 -mabs=2008` (MIPS XBurst2 specific)
- Output: ELF flags `0x70001407, noreorder, pic, cpic, nan2008, o32, mips32r2`

Cross-compiling matplotlib is **considerably harder** than `c_helper.so`:

- 3 C extensions to build (`ft2font`, `_image`, `_path`)
- Each must link against versions of libfreetype/libpng that **exactly match** what's on the printer (Entware: freetype 2.13.3, libpng 1.6.50)
- The Entware headers and libs would need to be downloaded into the codespace as a sysroot
- The Python target is 3.8 (for the venv) or 3.13 (for Entware Python) — different ABI, different `Py_ssize_t` etc.

Estimated effort: 2-4 hours of toolchain wrangling for an uncertain outcome. Not the path we ultimately took.

#### Path C: piwheels / prebuilt wheels

[piwheels.org](https://piwheels.org) is the standard prebuilt Python wheel repository. **It only supports armhf** (Raspberry Pi). MIPS is not supported. PyPI has zero MIPS wheels.

Result: no prebuilt option exists.

### 3.4 The actual solution — the K1 mod from GuppyScreen itself

After hours of investigation, the answer was **already on the printer**, dropped there months ago by the GuppyScreen installer:

```bash
$ ls -la /usr/data/guppyscreen/k1_mods/
-rwxr-xr-x  1 1001  root  101564 Apr 28  2024 ft2font.cpython-38-mipsel-linux-gnu.so
                                                ^^^^^^^^^^^^^^^^^^^^^^^^^^^^^^^^^^^^^^^^^^^^^^^^^^^^
                                                A precompiled, recent-freetype-compatible ft2font.so
```

The ballaswag GuppyScreen project specifically built and ships a `ft2font.cpython-38-mipsel-linux-gnu.so` that:

- Is statically compiled for MIPS little-endian / soft-float / mips32r2
- Targets Python 3.8 (matches the matplotlib 2.2.3 venv)
- Is **dynamically linked against a recent libfreetype** (probably 2.10+, compatible with 2.13)
- Is **101564 bytes** (vs 80828 for the original Creality one)

The guppyscreen `installer.sh` knows about this issue and handles it:

```sh
if [ ! -d "/usr/lib/python3.8/site-packages/matplotlib-2.2.3-py3.8.egg-info" ]; then
    echo "Not replacing matplotlib ft2font module. PSD graphs might not work"
else
    printf "Replacing matplotlib ft2font module for plotting PSD graphs\n"
    cp $K1_GUPPY_DIR/k1_mods/ft2font.cpython-38-mipsel-linux-gnu.so $FT2FONT_PATH
fi
```

### 3.5 Why our system was broken

The user had GuppyScreen installed but the ft2font swap **had never happened**. The most likely cause: a previous reinstall of matplotlib via Creality factory reset, or the GuppyScreen install ran but skipped the swap (maybe the egg-info dir wasn't where the installer expected it). Result: the original (broken) `ft2font.so` was still in place.

### 3.6 The fix

Three commands:

```bash
# 1. Backup the original (in case)
cp /usr/lib/python3.8/site-packages/matplotlib/ft2font.cpython-38-mipsel-linux-gnu.so \
   /usr/lib/python3.8/site-packages/matplotlib/ft2font.cpython-38-mipsel-linux-gnu.so.original

# 2. Install the K1 mod
cp /usr/data/guppyscreen/k1_mods/ft2font.cpython-38-mipsel-linux-gnu.so \
   /usr/lib/python3.8/site-packages/matplotlib/ft2font.cpython-38-mipsel-linux-gnu.so

# 3. Wipe matplotlib's font cache (forces re-scan with new lib)
rm -rf /root/.cache/matplotlib /root/.matplotlib
```

Verification:

```bash
$ md5sum /usr/lib/python3.8/site-packages/matplotlib/ft2font.cpython-38-mipsel-linux-gnu.so
7706852f09ad75472d15ff790ecc0d55
$ md5sum /usr/data/guppyscreen/k1_mods/ft2font.cpython-38-mipsel-linux-gnu.so
7706852f09ad75472d15ff790ecc0d55
# Match — swap successful.

$ /usr/share/klippy-env/bin/python -c "
import matplotlib; matplotlib.use('Agg')
import matplotlib.pyplot as plt
fig, ax = plt.subplots()
ax.plot([1,2,3])
fig.savefig('/tmp/test.png')
print('OK')
"
matplotlib + savefig OK
$ ls -la /tmp/test.png
-rw-r--r--  20117 May  7 16:14 /tmp/test.png
```

PNG generated, 20 KB. matplotlib works.

---

## 4. The CSV filename mismatch

After matplotlib was fixed, a new error appeared:

```
FileNotFoundError: [Errno 2] No such file or directory:
  '/tmp/raw_data_axis=1.000,-1.000_a.csv'
```

But the actual file present in `/tmp` was:

```
/tmp/raw_data_axis=1.000,-1.000,0.000_a.csv
```

Note the extra `,0.000` — Klipper mainline 2026 includes the **Z component** in the filename even when it's zero. Older Klipper versions (and the GuppyScreen macro, written against an older Klipper) used the format without the Z component.

### 4.1 Where the wrong path lives

```bash
$ grep -n "raw_data_axis" /usr/data/printer_data/config/GuppyScreen/guppy_cmd.cfg
56:  RUN_SHELL_COMMAND CMD=guppy_belts_calibration PARAMS=\
"-w {png_width} -l {png_height} -n -o {png_out_path} -k /usr/share/klipper \
 /tmp/raw_data_axis=1.000,-1.000_a.csv \
 /tmp/raw_data_axis=1.000,1.000_b.csv"
```

Two filename references on line 56, both with the old format. **And** a third issue: `-k /usr/share/klipper` points at a path that **doesn't exist** on this system (it's `/usr/data/klipper`).

### 4.2 The fix

```bash
cd /usr/data/printer_data/config/GuppyScreen/
cp guppy_cmd.cfg guppy_cmd.cfg.bak

# Add ',0.000' to both CSV filenames
sed -i 's|raw_data_axis=1.000,-1.000_a.csv|raw_data_axis=1.000,-1.000,0.000_a.csv|g' \
    guppy_cmd.cfg
sed -i 's|raw_data_axis=1.000,1.000_b.csv|raw_data_axis=1.000,1.000,0.000_b.csv|g' \
    guppy_cmd.cfg

# Fix the klipper directory
sed -i 's|-k /usr/share/klipper|-k /usr/data/klipper|g' guppy_cmd.cfg

# Verify
grep "raw_data_axis\|-k /usr" guppy_cmd.cfg
```

Then `FIRMWARE_RESTART` (so Klipper re-reads the macro definitions).

### 4.3 Direct test (no GuppyScreen UI needed)

If the CSVs are still in `/tmp`, the script can be tested directly:

```bash
/usr/data/printer_data/config/GuppyScreen/scripts/graph_belts.py \
  -w 8 -l 4.8 -n \
  -o /usr/data/printer_data/config/belts_calibration.png \
  -k /usr/data/klipper \
  /tmp/raw_data_axis=1.000,-1.000,0.000_a.csv \
  /tmp/raw_data_axis=1.000,1.000,0.000_b.csv
```

Expected (and obtained) output:

```
Warning: CSV filenames look to be different than expected
Warning: belts doesn't seem to have the correct name A and B
Belts estimated similarity: 93.1%
```

The two warnings are **cosmetic**. The script tries to extract belt names from the filename ("a" and "b") and complains about the new format, but the calculation itself is correct. PNG is generated, score is computed.

```bash
$ ls -la /usr/data/printer_data/config/belts_calibration.png
-rw-r--r-- 1 root root 77910 May  7 16:34 belts_calibration.png
```

77 KB PNG. Visually inspectable in Fluidd's File Manager.

---

## 5. The PNG dimension issue — observed but not fixed

### 5.1 Symptom

After fixing matplotlib (§3) and the CSV filenames (§4), the belt test runs to completion and a PNG is generated. **However**, when triggered from the GuppyScreen UI Belts button, the resulting `belts_calibration.png` has visible rendering defects:

- Title text overlapping with subtitle
- Axis labels superimposed on tick numbers
- Legend box bleeding into the chart area
- No `1e5` multiplier on the Y axis
- Generally cramped, hard to read

The same script run **manually from SSH** with `-w 8 -l 4.8` produces a clean, well-laid-out PNG. So the script works, but GuppyScreen passes different dimensions.

### 5.2 Root cause

The GuppyScreen binary (`/usr/data/guppyscreen/guppyscreen`) calls the macro with hardcoded dimension parameters:

```sh
$ strings /usr/data/guppyscreen/guppyscreen | grep "PNG_WIDTH"
GUPPY_BELTS_SHAPER_CALIBRATION PNG_OUT_PATH={} PNG_WIDTH={} PNG_HEIGHT={}
```

The actual values sent (verified by injecting a `RESPOND` debug line into the macro):

```
DEBUG: png_width=4.8 png_height=2.72
```

These dimensions match the Nebula Pad's screen resolution: 480 × 272 pixels at 100 DPI = 4.8" × 2.72". GuppyScreen tries to generate a PNG that exactly fills the screen.

The problem: **matplotlib cannot fit graph_belts.py's content in 480 × 272 pixels** without overlapping text. The script wasn't designed to scale gracefully to that size — its layout assumes ~800 × 480 minimum.

### 5.3 Attempted fix — and why it was reverted

We tested forcing the macro to ignore GuppyScreen's dimensions by hardcoding `8 × 4.8`:

```bash
# Tested but REVERTED — kept here as reference
python3 << 'PYEOF'
content = content.replace(
    "{% set png_width = params.PNG_WIDTH|default(8)|float %}",
    "{% set png_width = 8 %}"
)
# ...
PYEOF
```

This produced a clean, full-quality PNG (800 × 480 px). But it introduced a new cosmetic issue:

GuppyScreen displays `belts_calibration.png` **at native size, no scaling** (confirmed by `strings` inspection — no `lv_img_set_zoom` or `LV_IMG_SIZE_MODE_VIRTUAL` symbols in the binary). So an 800 × 480 PNG is shown at 800 × 480 on a 480 × 272 screen — only the top-left corner is visible.

Two equally imperfect outcomes:

| Approach | PNG quality | GuppyScreen display |
|---|---|---|
| Default (4.8 × 2.72) | Cramped text | Fits screen but illegible |
| Forced (8 × 4.8) | Clean | Cropped, only top-left visible |

**The proper solution is to produce BOTH formats** — one optimized for GuppyScreen's display, one for desktop viewing via Fluidd. See §6 below for the implemented dual-PNG strategy. The dimension-forcing patch was reverted in favor of this approach.

---

## 6. Dual-PNG strategy — small for GuppyScreen, large for PC

Rather than fighting GuppyScreen's hardcoded dimensions, we produce two PNGs per calibration: the one GuppyScreen wants (small, fits the screen), plus a desktop-readable one (large, viewable via Fluidd). Same test data, two renderings.

### 6.1 Architecture overview

```
Belt test:
  GUPPY_BELTS_SHAPER_CALIBRATION (macro)
    ├─ TEST_RESONANCES AXIS=1,1  → /tmp/raw_data_axis=...,0.000_b.csv
    ├─ TEST_RESONANCES AXIS=1,-1 → /tmp/raw_data_axis=...,0.000_a.csv
    ├─ RUN_SHELL_COMMAND guppy_belts_calibration
    │   → graph_belts.py -w 4.8 -l 2.72 → belts_calibration.png       [GuppyScreen]
    └─ RUN_SHELL_COMMAND guppy_belts_calibration_pc
        → gen_belts_png.sh (wrapper)
            → mkdir -p printer_calibration_graphs/
            → graph_belts.py -w 8 -l 4.8 → belts_calibration_PC_SIZE_<timestamp>.png   [PC]

Input Shaper test:
  Triggered by GuppyScreen UI button (bypasses GUPPY_SHAPERS macro,
  calls TEST_RESONANCES + guppy_input_shaper directly)
    ├─ TEST_RESONANCES AXIS=X NAME=x → /tmp/resonances_x_x.csv
    ├─ RUN_SHELL_COMMAND guppy_input_shaper
    │   → gen_shaper_combo.sh (wrapper)
    │       ├─ calibrate_shaper.py CSV → resonances_x.png            [GuppyScreen]
    │       └─ calibrate_shaper.py CSV -w 8 -l 4.8
    │           → resonances_x_PC_SIZE_<timestamp>.png               [PC]
    └─ same for Y axis
```

### 6.2 Why two architectures (macro vs shell-command wrapper)

The two features have different control flow:

- **Belts**: GuppyScreen calls the macro `GUPPY_BELTS_SHAPER_CALIBRATION`. The macro is fully under our control — we add a second `RUN_SHELL_COMMAND` for the PC version.
- **Input Shaper**: GuppyScreen **bypasses** the `GUPPY_SHAPERS` macro. Its binary calls `TEST_RESONANCES AXIS=X NAME=x` directly (confirmed by `strings` inspection), then triggers the shell command `guppy_input_shaper`. We can't add lines to a code path we don't control.

The workaround for Input Shaper: redirect `guppy_input_shaper` to a wrapper script that produces both PNGs. GuppyScreen still calls one command; the wrapper internally fans out.

### 6.3 The shaper combo wrapper

`/usr/data/printer_data/config/GuppyScreen/scripts/gen_shaper_combo.sh`:

```sh
#!/bin/sh
set -e

# 1. GuppyScreen sized PNG (original behavior, pass-through args)
/usr/data/printer_data/config/GuppyScreen/scripts/calibrate_shaper.py "$@"

# 2. Detect axis from CSV path
CSV="$1"
AXIS=$(echo "$CSV" | grep -oE "resonances_[xy]" | sed 's/resonances_//')
[ -z "$AXIS" ] && AXIS="unknown"

# 3. PC sized PNG
OUT_DIR="/usr/data/printer_data/config/printer_calibration_graphs"
mkdir -p "$OUT_DIR"
TIMESTAMP=$(date +%Y%m%d_%H%M%S)
OUT_PNG="$OUT_DIR/resonances_${AXIS}_PC_SIZE_${TIMESTAMP}.png"

/usr/data/printer_data/config/GuppyScreen/scripts/calibrate_shaper.py \
    "$CSV" -o "$OUT_PNG" -w 8 -l 4.8

echo "PC-sized shaper PNG: $OUT_PNG"
```

And `gcode_shell_command guppy_input_shaper` is repointed to it:

```ini
[gcode_shell_command guppy_input_shaper]
command: /usr/data/printer_data/config/GuppyScreen/scripts/gen_shaper_combo.sh
timeout: 600.0
verbose: True
```

GuppyScreen still calls `guppy_input_shaper` exactly as before. The wrapper produces the small PNG (for GuppyScreen's display, identical to before), then transparently makes a PC-sized one.

### 6.4 The belts wrapper and macro patch

`/usr/data/printer_data/config/GuppyScreen/scripts/gen_belts_png.sh`:

```sh
#!/bin/sh
set -e

CSV_A="$1"
CSV_B="$2"

OUT_DIR="/usr/data/printer_data/config/printer_calibration_graphs"
mkdir -p "$OUT_DIR"
TIMESTAMP=$(date +%Y%m%d_%H%M%S)
OUT_PNG="$OUT_DIR/belts_calibration_PC_SIZE_${TIMESTAMP}.png"

/usr/data/printer_data/config/GuppyScreen/scripts/graph_belts.py \
    -w 8 -l 4.8 -n -o "$OUT_PNG" \
    -k /usr/data/klipper \
    "$CSV_A" "$CSV_B"

echo "PC-sized belts PNG: $OUT_PNG"
```

A new shell command in `guppy_cmd.cfg`:

```ini
[gcode_shell_command guppy_belts_calibration_pc]
command: /usr/data/printer_data/config/GuppyScreen/scripts/gen_belts_png.sh
timeout: 600.0
verbose: True
```

And the macro `GUPPY_BELTS_SHAPER_CALIBRATION` gets one extra `RUN_SHELL_COMMAND` at the end:

```ini
  RUN_SHELL_COMMAND CMD=guppy_belts_calibration PARAMS="-w {png_width} -l {png_height} -n -o {png_out_path} -k /usr/data/klipper /tmp/raw_data_axis=1.000,-1.000,0.000_a.csv /tmp/raw_data_axis=1.000,1.000,0.000_b.csv"
  RESPOND MSG="Generating Belts Plot (PC size)..."
  RUN_SHELL_COMMAND CMD=guppy_belts_calibration_pc PARAMS="/tmp/raw_data_axis=1.000,-1.000,0.000_a.csv /tmp/raw_data_axis=1.000,1.000,0.000_b.csv"
```

### 6.5 Output naming convention

PC-sized PNGs go into a dedicated subdirectory with timestamped filenames:

```
/usr/data/printer_data/config/printer_calibration_graphs/
├── belts_calibration_PC_SIZE_20260511_040339.png
├── resonances_x_PC_SIZE_20260511_041103.png
└── resonances_y_PC_SIZE_20260511_041152.png
```

Benefits:
- **History preserved** — every test produces a new file, no overwrite
- **GuppyScreen files untouched** — `resonances_x.png`, `resonances_y.png`, `belts_calibration.png` stay where GuppyScreen expects them
- **Easy cleanup** — delete the whole subdirectory to reset history; wrappers re-create it on next run

### 6.6 Side fix — calibrate_shaper.py shebang

When testing the Input Shaper path standalone (without GuppyScreen), `calibrate_shaper.py` failed with:

```
ModuleNotFoundError: No module named 'matplotlib'
```

Cause: the script's shebang `#!/usr/bin/env python3` resolves to `/opt/bin/python3` (Entware Python 3.13), which doesn't have matplotlib. Only the legacy Klipper venv at `/usr/share/klippy-env/bin/python` has the patched matplotlib 2.2.3 from §3.

Fix:

```bash
sed -i '1c#!/usr/share/klippy-env/bin/python' \
    /usr/data/printer_data/config/GuppyScreen/scripts/calibrate_shaper.py
```

`graph_belts.py` already had the correct shebang.

---

## 7. Cosmetic improvements to graph_belts.py

The Frix-x `graph_belts.py` script emits two warnings on every Klipper-native CSV input, and uses A/B belt labels that don't match the Ender 5 Max's physical labeling.

### 7.1 Warning 1 — "CSV filenames look to be different than expected"

The script tries to parse a date/time from the filename:

```python
# Lines ~521-527 of graph_belts.py
try:
    filename = lognames[0].split('/')[-1]
    dt = datetime.strptime(f"{filename.split('_')[1]} {filename.split('_')[2]}",
                          "%Y%m%d %H%M%S")
    title_line2 = dt.strftime('%x %X')
except:
    print("Warning: CSV filenames look to be different than expected ...")
    title_line2 = lognames[0].split('/')[-1] + " / " + lognames[1].split('/')[-1]
```

It expects the historic Klippain-shaketune filename format `belt_a_YYYYMMDD_HHMMSS_a.csv`. But Klipper mainline 2026 generates `raw_data_axis=1.000,-1.000,0.000_a.csv` — no date in the name. The except branch fires every time.

**Fix**: add a graceful fallback that uses the file's modification time:

```python
try:
    filename = lognames[0].split('/')[-1]
    dt = datetime.strptime(f"{filename.split('_')[1]} {filename.split('_')[2]}",
                          "%Y%m%d %H%M%S")
    title_line2 = dt.strftime('%x %X')
except:
    # Klipper-native format: use file mtime as title date
    try:
        import os
        mtime = os.path.getmtime(lognames[0])
        dt = datetime.fromtimestamp(mtime)
        title_line2 = dt.strftime('%x %X')
    except:
        title_line2 = lognames[0].split('/')[-1] + " / " + lognames[1].split('/')[-1]
```

Result: title now reads "05/11/26 04:03:39" (file creation time) instead of a long messy filename.

### 7.2 Warning 2 — "belts doesn't seem to have the correct name A and B"

The script extracts the belt letter from the filename:

```python
# Line ~297
signal1_belt = (lognames[0].split('/')[-1]).split('_')[-1][0]
# → for raw_data_axis=...,0.000_a.csv: '_a.csv'.split('_')[-1][0] = 'a' (lowercase)
```

Then compares case-sensitively:

```python
if signal1_belt == 'A' and signal2_belt == 'B':   # 'a' != 'A'  → fails
```

Klipper writes lowercase filenames; the script expects uppercase. Mismatch → warning fires every time.

**Fix**: uppercase the extracted letter:

```python
signal1_belt = (lognames[0].split('/')[-1]).split('_')[-1][0].upper()
signal2_belt = (lognames[1].split('/')[-1]).split('_')[-1][0].upper()
```

### 7.3 Belt naming — A/B vs X/Y

On the Ender 5 Max (a true CoreXY printer), the convention in the upstream `graph_belts.py` is to label belts as "A" and "B" — technically correct since neither belt drives X or Y independently. However, the user-facing convention in Creality's documentation and the E5M-CK project is **"X belt"** and **"Y belt"**, identifying them by which stepper drives them.

**Empirical verification via diagonal moves**:

```
G91 G0 X10 Y-10 F3000   → only stepper_x rotates → moves the "X belt"
G91 G0 X10 Y10  F3000   → only stepper_y rotates → moves the "Y belt"
```

(Test confirmed on the user's E5M.)

In Klipper CoreXY kinematics, `AXIS=1,-1` exercises stepper_x alone (= X belt), and `AXIS=1,1` exercises stepper_y alone (= Y belt). The macro produces:

```
TEST_RESONANCES AXIS=1,-1 NAME=a  →  /tmp/raw_data_axis=...,0.000_a.csv  →  X belt
TEST_RESONANCES AXIS=1,1  NAME=b  →  /tmp/raw_data_axis=...,0.000_b.csv  →  Y belt
```

**Fix**: remap A→"X belt", B→"Y belt" in the chart legend, and remove the redundant "Belt " prefix in the plot label:

```python
# E5M-CK: remap A/B (CoreXY convention) to X/Y (physical belts on Ender 5 Max)
#   Belt A = stepper_x rotation = X belt (verified via STEPPER_BUZZ + diagonal moves)
#   Belt B = stepper_y rotation = Y belt
if signal1_belt == 'A' and signal2_belt == 'B':
    signal1_belt = "X belt"
    signal2_belt = "Y belt"
elif signal1_belt == 'B' and signal2_belt == 'A':
    signal1_belt = "Y belt"
    signal2_belt = "X belt"
else:
    print("Warning: belts doesn't seem to have the correct name A and B ...")

# And in the plot calls:
ax.plot(signal1.freqs, signal1.psd, label=signal1_belt, ...)   # was: "Belt " + signal1_belt
ax.plot(signal2.freqs, signal2.psd, label=signal2_belt, ...)
```

The peak annotations (`A1`, `A2`, `B1`, `B2`...) are **unaffected** — they come from a separate `ALPHABET[paired_peak_count]` variable and continue to use sequential letters per detected peak pair.

### 7.4 Combined patch

All three fixes applied via one Python script that reads, replaces, and writes back. See `installs/patch_graph_belts.sh` in the E5M-CK repository for the deployable version. Backup is preserved as `graph_belts.py.bak` and `graph_belts.py.bak2`.

---

## 8. The duplicated-logs bug

After deploying the dual-PNG strategy, every macro message and every shell command appeared **twice** in the Fluidd console:

```
Belts comparative frequency profile generation (GuppyScreen)...
Belts comparative frequency profile generation (GuppyScreen)...
// Running Command {guppy_belts_calibration}...:
// Running Command {guppy_belts_calibration}...:
```

Root cause discovered via:

```bash
$ grep -rn "include.*guppy_cmd\|include.*GuppyScreen" /usr/data/printer_data/config/*.cfg
/usr/data/printer_data/config/printer-20260507_105940.cfg:12:[include GuppyScreen/*.cfg]
/usr/data/printer_data/config/printer.cfg:13:[include GuppyScreen/*.cfg]
```

A **dated backup of printer.cfg** had been left in the `config/` directory. Klipper loads every `.cfg` in that directory (since `printer.cfg` is just one entry of many), and both files contain `[include GuppyScreen/*.cfg]` — so all GuppyScreen macros got loaded twice, all shell commands got registered twice, and every G-code command got executed twice.

**Fix**: move any backup `.cfg` files **out** of `printer_data/config/`:

```bash
mkdir -p /usr/data/printer_data/backup_cfg
mv /usr/data/printer_data/config/printer-*.cfg \
   /usr/data/printer_data/backup_cfg/
```

**Lesson**: Klipper's `[include]` wildcard matching is **directory-wide**, not just for files referenced from `printer.cfg`. Renaming to `.bak` extension is enough to exclude from the include scan; moving to a different folder is safer.

---

## 9. Validation procedure — full belt test

### 9.1 Prerequisites

- ADXL345 bridge installed and working (`MEMO_adxl345_bridge_ENG.md`).
- `adxl345_rate: 1600` in `[accel_chip_proxy]` block.
- ft2font swap done (§3.6).
- guppy_cmd.cfg patched for CSV filenames (§4.2).
- Dual-PNG strategy installed (§6): wrappers in place, `guppy_input_shaper` redirected to combo, belts macro extended.
- graph_belts.py cosmetic patches applied (§7).
- No duplicate `[include]`-bearing cfg in `config/` (§8).
- Klipper restarted with FIRMWARE_RESTART so macros are reloaded.

### 9.2 Run from GuppyScreen

Touch screen → **Belts** button.

GuppyScreen calls `GUPPY_BELTS_SHAPER_CALIBRATION FREQ_START=5 FREQ_END=44.6 HZ_PER_SEC=2 PNG_WIDTH=4.8 PNG_HEIGHT=2.72`. The test runs ~3 minutes, then **two PNGs** are produced:

- `/usr/data/printer_data/config/belts_calibration.png` — small (480×272), for GuppyScreen's display
- `/usr/data/printer_data/config/printer_calibration_graphs/belts_calibration_PC_SIZE_<timestamp>.png` — large (800×480), for desktop viewing

Similarly, **Input Shaper** button produces small + PC PNGs per axis.

### 9.3 Run from Fluidd console

```
GUPPY_BELTS_SHAPER_CALIBRATION FREQ_START=5 FREQ_END=44.6 HZ_PER_SEC=2
```

`GUPPY_SHAPERS` can also be invoked from Fluidd console but **isn't** what the GuppyScreen Input Shaper button calls — the button bypasses the macro and calls `TEST_RESONANCES` + `guppy_input_shaper` directly.

### 9.4 Manual run (for debugging)

```
TEST_RESONANCES AXIS=1,1 OUTPUT=raw_data
TEST_RESONANCES AXIS=1,-1 OUTPUT=raw_data
RUN_SHELL_COMMAND CMD=guppy_belts_calibration PARAMS="-w 8 -l 4.8 -n \
  -o /usr/data/printer_data/config/belts_calibration.png \
  -k /usr/data/klipper \
  /tmp/raw_data_axis=1.000,-1.000,0.000_a.csv \
  /tmp/raw_data_axis=1.000,1.000,0.000_b.csv"
```

### 9.5 Reading the result

The PC-sized PNG (`printer_calibration_graphs/belts_calibration_PC_SIZE_*.png`) contains:

- **PSD curves**: `X belt` (purple) and `Y belt` (orange), overlaid. Peaks should overlap closely if belts are balanced.
- **Relax region**: pale green band; peaks below this threshold are ignored.
- **Annotated peaks**: black `×` markers with labels (`A1`/`A2` for first paired peak pair, `B1`/`B2` for second, etc.).
- **Score & table**: top-right, similarity percentage and per-peak frequency/amplitude deltas.

Interpretation of similarity score:

| Score | Meaning |
|---|---|
| > 95% | Excellent — belts perfectly balanced |
| 90-95% | Good — minor imbalance, prints will be fine |
| 85-90% | Acceptable — printable, but consider retensioning |
| < 85% | Imbalanced — retension before serious printing |

The user's E5M consistently scored **84.9% – 92.6%** across multiple measurements — within the "acceptable" to "good" band.

### 9.6 Reading the Input Shaper results

The PC-sized PNGs (`printer_calibration_graphs/resonances_x_PC_SIZE_*.png` and `_y_*`) show:

- **Power spectral density** of the axis frequency response
- **Shapers overlaid**: ZV, MZV, EI, 2HUMP_EI, 3HUMP_EI — each with the residual vibration percentage, smoothing factor, and `max_accel` ceiling
- **Recommended shaper**: highlighted in the legend

The recommendation appears in the Fluidd console too, as JSON:

```
{"shapers": {"zv": {...}, "mzv": {...}, ...}, "best": "mzv", ...}
```

GuppyScreen displays the small PNGs and offers a `Save` button to write the recommendation into `printer.cfg` via `SAVE_INPUT_SHAPER`.

---

## 10. Failure modes encountered (and resolved)

| Symptom | Root cause | Fix |
|---|---|---|
| `Stepper too far in past` during TEST_RESONANCES | UART link saturated at 3200 Hz | `adxl345_rate: 1600` in proxy config |
| `terminate ... Couldn't close file. Aborted` on PNG generation | matplotlib 2.2.3 ft2font.so vs freetype 2.13 ABI mismatch | Swap to `/usr/data/guppyscreen/k1_mods/ft2font.cpython-38-mipsel-linux-gnu.so` |
| `FileNotFoundError /tmp/raw_data_axis=1.000,-1.000_a.csv` | Klipper mainline filename format changed (added Z component) | sed in `guppy_cmd.cfg` to add `,0.000` |
| graph_belts.py imports fail | wrong `-k` path | Change `-k /usr/share/klipper` to `-k /usr/data/klipper` |
| PNG visually broken on PC view | GuppyScreen sends `PNG_WIDTH=4.8 PNG_HEIGHT=2.72` (480×272 px) — too small for matplotlib layout | Dual-PNG strategy (§6): small for GuppyScreen, large for PC |
| `ModuleNotFoundError: No module named 'matplotlib'` running calibrate_shaper.py | Shebang `/usr/bin/env python3` resolves to Entware (no matplotlib) | Change shebang to `/usr/share/klippy-env/bin/python` |
| Input Shaper button doesn't produce PC PNG | GuppyScreen bypasses `GUPPY_SHAPERS` macro and calls shell command directly | Wrap shell command with `gen_shaper_combo.sh` that produces both sizes |
| Every macro line/command duplicated in Fluidd console | A dated backup `.cfg` in `config/` got auto-included | Move backups to a folder outside `config/` |
| Warning "CSV filenames look to be different than expected" | graph_belts.py expects historic Klippain filename format | Add fallback to `os.path.getmtime()` for title date |
| Warning "belts doesn't seem to have the correct name A and B" | Case-sensitive comparison of lowercase filename letter | `.upper()` on extracted letter |
| Legend says "Belt A" / "Belt B" — confusing for E5M users | CoreXY convention vs Creality user-facing labeling | Remap to `X belt` / `Y belt` |

---

## 11. What we tried that didn't work — record for future reference

These are the dead-ends we walked into. Listing them here so future maintainers don't repeat them.

### 11.1 Disabling subset of fonts

Cycled through STIX → DejaVuSerif* → CM* → DejaVuSans* one by one. Each round, the next font in alphabetical order would crash. Confirmed not a font-specific bug.

### 11.2 Forcing specific matplotlib backend

Tried `matplotlib.use('Agg')` before importing pyplot. Crashes regardless. The font_manager scan happens during pyplot init, before backend selection matters for fonts.

### 11.3 Compiling matplotlib natively on the printer

Tried `pip install matplotlib<3.6` with `TMPDIR=/usr/data/pip-tmp` etc. Failed during the `ft2font` C extension build because Entware doesn't ship freetype dev headers.

### 11.4 Trying to find a prebuilt MIPS wheel on PyPI / piwheels

None exist. piwheels is armhf-only. PyPI doesn't ship MIPS wheels for matplotlib at any version.

### 11.5 Cross-compiling matplotlib in Codespaces

Theoretically possible (we have the toolchain working for `c_helper.so` already). Practically: 3 C extensions, multiple deps to ABI-match against the printer's Entware libs, 2-4 hours of work for uncertain results.

Not pursued because we found the K1 mod ft2font.so already on the printer, which solved the problem in 30 seconds.

### 11.6 Patching the GuppyScreen binary for image scaling

Tried locating LVGL image-scaling symbols (`lv_img_set_zoom`, `LV_IMG_SIZE_MODE_VIRTUAL`) in the binary:

```bash
$ strings /usr/data/guppyscreen/guppyscreen | grep -iE "lv_img|img_set|set_zoom|size_mode"
# (empty)
```

The `BeltsCalibrationPanel` C++ class hardcodes the image widget. Patching the binary would require recompiling GuppyScreen from source — out of scope. The dual-PNG strategy (§6) is the alternative.

### 11.7 Forcing 8×4.8 dimensions for everything

We tested overriding GuppyScreen's `PNG_WIDTH=4.8 PNG_HEIGHT=2.72` to always use 8×4.8 in the macro. PNG was clean, but GuppyScreen's on-screen display showed only the top-left quadrant (no auto-scaling — see §11.6). The dual-PNG strategy was preferred because it serves both audiences cleanly: GuppyScreen sees what it wants, the user sees a proper graph on the PC.

### 11.8 Modifying calibrate_shaper.py and graph_belts.py in place

Considered modifying the Python scripts directly to produce both sizes in one call. Rejected because:

- Touches third-party code that may get updated/overwritten by future GuppyScreen installs
- The wrapper-script approach is more transparent and easier to maintain
- Performance: a second call adds only ~5 seconds to a 3-minute test

The cosmetic patches in §7 are a different matter — they're small targeted edits with clear backups, and the affected code paths aren't expected to change upstream.

---

## 12. Recap — minimum commands

Full deployment, assuming the ADXL345 bridge is already in place:

```bash
# ─── §3 — Fix matplotlib ft2font ABI ───────────────────
cp /usr/data/guppyscreen/k1_mods/ft2font.cpython-38-mipsel-linux-gnu.so \
   /usr/lib/python3.8/site-packages/matplotlib/ft2font.cpython-38-mipsel-linux-gnu.so
rm -rf /root/.cache/matplotlib /root/.matplotlib

# ─── §4 — Fix CSV filename format and -k path ──────────
sed -i 's|raw_data_axis=1.000,-1.000_a.csv|raw_data_axis=1.000,-1.000,0.000_a.csv|g' \
    /usr/data/printer_data/config/GuppyScreen/guppy_cmd.cfg
sed -i 's|raw_data_axis=1.000,1.000_b.csv|raw_data_axis=1.000,1.000,0.000_b.csv|g' \
    /usr/data/printer_data/config/GuppyScreen/guppy_cmd.cfg
sed -i 's|-k /usr/share/klipper|-k /usr/data/klipper|g' \
    /usr/data/printer_data/config/GuppyScreen/guppy_cmd.cfg

# ─── §6.6 — Fix calibrate_shaper.py shebang ────────────
sed -i '1c#!/usr/share/klippy-env/bin/python' \
    /usr/data/printer_data/config/GuppyScreen/scripts/calibrate_shaper.py

# ─── §6 — Install dual-PNG wrappers ────────────────────
wget --no-check-certificate \
  https://raw.githubusercontent.com/christianKEL/E5M-CK/main/installs/gen_belts_png.sh \
  -O /usr/data/printer_data/config/GuppyScreen/scripts/gen_belts_png.sh
wget --no-check-certificate \
  https://raw.githubusercontent.com/christianKEL/E5M-CK/main/installs/gen_shaper_png.sh \
  -O /usr/data/printer_data/config/GuppyScreen/scripts/gen_shaper_png.sh
# Combo wrapper (intercepts guppy_input_shaper)
wget --no-check-certificate \
  https://raw.githubusercontent.com/christianKEL/E5M-CK/main/installs/gen_shaper_combo.sh \
  -O /usr/data/printer_data/config/GuppyScreen/scripts/gen_shaper_combo.sh
chmod +x /usr/data/printer_data/config/GuppyScreen/scripts/gen_*.sh

# Patch guppy_cmd.cfg: add new shell commands + extend belts macro
# (see PATCH_guppy_cmd.txt in repo for the full Python script)

# ─── §7 — Apply graph_belts.py cosmetic patches ────────
# (see installs/patch_graph_belts.sh in repo)

# ─── §8 — Move any duplicate cfg backups out ───────────
mkdir -p /usr/data/printer_data/backup_cfg
mv /usr/data/printer_data/config/printer-*.cfg \
   /usr/data/printer_data/backup_cfg/ 2>/dev/null || true

# ─── Restart and validate ──────────────────────────────
/etc/init.d/S55klipper_service restart

# Test from GuppyScreen UI: Belts button + Input Shaper button.
# Verify outputs:
ls -la /usr/data/printer_data/config/belts_calibration.png
ls -la /usr/data/printer_data/config/resonances_x.png
ls -la /usr/data/printer_data/config/resonances_y.png
ls -la /usr/data/printer_data/config/printer_calibration_graphs/
```

---

## 13. Open questions / future work

### 13.1 Why didn't the GuppyScreen installer swap ft2font?

The installer logic is:

```sh
if [ ! -d "/usr/lib/python3.8/site-packages/matplotlib-2.2.3-py3.8.egg-info" ]; then
    echo "Not replacing matplotlib ft2font module."
else
    cp $K1_GUPPY_DIR/k1_mods/ft2font.cpython-38-mipsel-linux-gnu.so $FT2FONT_PATH
fi
```

It checks for the **egg-info** directory of matplotlib 2.2.3. If present → swap. If absent → skip.

On the user's system, the egg-info was either:
- Not present at install time (matplotlib was reinstalled/repaired afterwards)
- Or present but at a slightly different path

Either way, the conditional fired the wrong branch. **Fix would be**: drop the conditional and always swap. But that's a change to ballaswag's installer, not something to do unilaterally.

### 13.2 Should the bridge installer also handle the dual-PNG setup?

Plausible enhancement to `install_adxl_patch_v2.sh`: detect missing wrappers and offer to install them. This would consolidate all GuppyScreen fixes into a single install command.

Not a priority — each individual fix is well-documented and reversible.

### 13.3 Should we patch graph_belts.py for the small-display case?

Currently the GuppyScreen-sized PNG (480×272) has cramped text. A genuine fix would patch `graph_belts.py` to detect a small canvas and adapt the layout: smaller fonts, no detailed legend, tighter ratios.

Estimated effort: 30-60 minutes of Python work + iterative testing. Not done because:

- The PC-sized PNG (§6) covers the desktop use case
- Belt tests are infrequent (every few months at most)
- The cramped on-screen rendering is mostly cosmetic — the user can read the similarity score, which is what matters operationally

Future enhancement candidate.

### 13.4 Should we upstream the cosmetic patches?

The §7 fixes (warning suppression, A/B → X/Y remap, mtime fallback) are arguably useful for all CoreXY users running Klipper mainline, not just E5M-CK. They could be submitted to ballaswag's `guppyscreen` repo (or the upstream Frix-x `klippain-shaketune` if they share the same `graph_belts.py`). Out of scope for this project, but a candidate for a clean PR.

---

## 14. Repository layout

```
E5M-CK/
├── files/
│   ├── adxl345_creality.py
│   ├── accel_chip_proxy.py
│   └── ft2font.cpython-38-mipsel-linux-gnu.so   ← optional mirror of K1 mod
├── installs/
│   ├── install_adxl_patch_v2.sh
│   ├── gen_belts_png.sh                          ← dual-PNG wrapper (belts)
│   ├── gen_shaper_png.sh                         ← dual-PNG wrapper (shaper, standalone)
│   ├── gen_shaper_combo.sh                       ← combo wrapper (intercepts guppy_input_shaper)
│   ├── PATCH_guppy_cmd.txt                       ← manual patch instructions
│   └── patch_graph_belts.sh                      ← cosmetic patches (§7)
└── docs/
    ├── MEMO_c_helper_ENG.md
    ├── MEMO_adxl345_bridge_ENG.md
    └── MEMO_guppyscreen_belts_ENG.md   ← this file
```

The K1-mod `ft2font.cpython-38-mipsel-linux-gnu.so` is also retrievable directly from the GuppyScreen GitHub releases (asset `guppyscreen.tar.gz` → `k1_mods/ft2font.cpython-38-mipsel-linux-gnu.so`):

- https://github.com/ballaswag/guppyscreen/releases

MD5 of the working version: `7706852f09ad75472d15ff790ecc0d55` (101564 bytes).

---

*Document written in May 2026 as part of the E5M-CK project. Companion to `MEMO_c_helper_ENG.md` and `MEMO_adxl345_bridge_ENG.md`.*

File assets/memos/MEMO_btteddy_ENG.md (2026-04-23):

# TECHNICAL MEMO — Building `btteddy.uf2`

## Klipper mainline firmware for the BTT Eddy USB (RP2040)

**Author:** Christian KELHETTER
**Project:** E5M-CK — https://github.com/christianKEL/E5M-CK
**Date:** April 2026

---

## 1. Context and problem statement

### 1.1 What is `btteddy.uf2`?

`btteddy.uf2` is the **Klipper firmware** that runs on the RP2040 microcontroller embedded in the BTT Eddy USB. This firmware:

- Drives the LDC1612 chip (eddy-current sensor) over I2C.
- Sends frequency measurements to the host over USB.
- Reads the Eddy's onboard thermistor (on GPIO26).
- Applies temperature corrections to the LDC signal.

### 1.2 Why build it yourself?

BTT does provide pre-built firmware on its GitHub repository. However:

1. **Klipper version:** the pre-built BTT firmware is often tied to a Klipper version that does not match the one installed on the Nebula. When versions diverge, Klipper will log at startup:

   ```
   MCU 'eddy' protocol error: command format mismatch
   ```

2. **Binary format:** BTT sometimes distributes the firmware as a `.bin` (intended for flashing via `rp2040load` or similar). On the Nebula Pad we have neither `rp2040load` nor `openocd` — the only viable flashing method is the UF2 method (copying a file onto the USB disk that the RP2040 exposes in BOOT mode).

3. **Mainline consistency:** the Eddy's firmware must be built from **the same commit** as the Klipper installed on the Nebula. Otherwise the message layouts between host and MCU may be incompatible.

Building it yourself solves all three problems.

### 1.3 The RP2040

The **Raspberry Pi RP2040** embedded in the BTT Eddy is a dual-core ARM Cortex-M0+ microcontroller with:
- 264 KB of SRAM.
- No internal flash — the firmware lives on an external SPI flash chip.
- **BOOTSEL** mode activated by the BOOT button: the RP2040 then exposes itself as a FAT16 USB disk that accepts a `.uf2` file.

The **UF2 (USB Flashing Format)** was designed by Microsoft to make flashing dead simple: drop a `.uf2` onto the USB disk exposed by the bootloader, the firmware is automatically written to flash, and the RP2040 reboots.

---

## 2. Build environment

### 2.1 Required architecture

Building Klipper's RP2040 firmware requires:
- An ARM cross-compiler (`arm-none-eabi-gcc`).
- The `make` + `kconfig` build system.
- An x86_64 or ARM64 Linux host (both work for this target).

Unlike `c_helper.so` which absolutely requires an x86_64 host to run the Ingenic toolchain, building the RP2040 firmware can technically be done on any Linux host (the `arm-none-eabi-gcc` toolchain exists for both x86_64 and ARM64).

### 2.2 Recommended environment

For **consistency with the `c_helper.so` workflow** and to avoid setting up a local build environment, we use the **same GitHub Codespace** as the one used to build `c_helper.so` (see the `MEMO_c_helper.md` memo).

Benefits:
- Same environment for `c_helper.so` and `btteddy.uf2` — same Klipper commit.
- No local installation to maintain.
- Excellent build performance (~30 seconds).

### 2.3 Installing prerequisites

In the codespace:

```bash
# The ARM toolchain is usually pre-installed on Ubuntu Codespaces.
# If missing:
sudo apt update
sudo apt install -y gcc-arm-none-eabi build-essential

# Verify
arm-none-eabi-gcc --version
# Expected: arm-none-eabi-gcc (15:...) 10.3.1 or newer
```

Klipper recommends GCC 9 or newer for the RP2040. GCC 10+ works without issue.

### 2.4 Klipper source

If a codespace was already used for `c_helper.so`, Klipper is already cloned at `/workspaces/klipper`. Otherwise:

```bash
git clone https://github.com/Klipper3d/klipper.git /workspaces/klipper
cd /workspaces/klipper
```

**Important:** to ensure compatibility with the Nebula host, use **the same commit** as the one installed on the Nebula. The commit can be obtained from:

```bash
# On the Nebula
cd /usr/data/klipper
git rev-parse HEAD
# Example: 373f200ca5a8c5e0...
```

Then in the Codespace, before building:

```bash
cd /workspaces/klipper
git checkout 373f200ca   # same hash as on the Nebula
```

---

## 3. `make menuconfig` configuration

### 3.1 Launch

```bash
cd /workspaces/klipper
make clean
make menuconfig
```

An ncurses menu appears in the codespace terminal.

### 3.2 Settings for the BTT Eddy USB

Settings to apply in `menuconfig`:

| Option | Value | Comment |
|---|---|---|
| Micro-controller Architecture | **Raspberry Pi RP2040** | The BTT Eddy USB core |
| Processor model | **rp2040** | Only option available in this branch |
| Bootloader offset | **No bootloader** | The RP2040 has a ROM bootloader; no second bootloader needed |
| Flash chip | **GENERIC_03H with CLKDIV 4** | Matches the SPI flash soldered on the BTT Eddy |
| Communication interface | **USB (on GPIO 19/20)** | The Eddy talks to the host over USB only (no UART, no CAN) |
| USB ids | Keep defaults | Klipper uses its own VID/PID by default |
| CanBoot options | **(not applicable)** | No CAN on the USB Eddy |

**Note on Flash chip:** `GENERIC_03H with CLKDIV 4` matches BTT's Eddy products. `GENERIC_03H` refers to SPI read command `0x03` (Read Data), supported by the vast majority of flash chips. `CLKDIV 4` sets the SPI bus frequency to one quarter of the system clock, matching the nominal rate of the chip in use.

If firmware built with `GENERIC_03H` does not boot on your Eddy, try `W25Q080 with CLKDIV 2` (RP2040 standard factory value).

### 3.3 Saving and exit

In the `menuconfig` menu:
- **Y/N** keys to toggle an option.
- **Enter** to enter a submenu.
- **Escape** to go up.
- **Q** to quit. If changes were made, answer **Yes** to "Save configuration?".

The `.config` file at the project root now holds the configuration.

### 3.4 Alternative — direct `.config`

Rather than running `menuconfig`, the `.config` file can be created directly:

```bash
cat > /workspaces/klipper/.config << 'EOF'
# Micro-controller Architecture
CONFIG_MACH_RP2040=y
CONFIG_MCU="rp2040"

# Bootloader
CONFIG_RP2040_HAVE_BOOTLOADER=n

# Flash chip
CONFIG_RP2040_FLASH_GENERIC_03H=y
CONFIG_RP2040_FLASH_CLKDIV=4

# Communication
CONFIG_USBSERIAL=y

CONFIG_CLOCK_FREQ=12000000
CONFIG_USB_VENDOR_ID=0x1d50
CONFIG_USB_DEVICE_ID=0x614e
EOF
```

This is faster for an automated build.

---

## 4. Build

### 4.1 Compile

```bash
cd /workspaces/klipper
make
```

Typical output:

```
  Building out/autoconf.h
  Compiling out/src/sched.o
  Compiling out/src/command.o
  ...
  Compiling out/src/rp2040/main.o
  Compiling out/src/rp2040/usbserial.o
  ...
  Linking out/klipper.elf
  Creating hex file out/klipper.elf.hex
  Creating bin file out/klipper.bin
  Converting to uf2 file out/klipper.uf2
```

Duration: ~20 to 40 seconds on a standard codespace.

### 4.2 Output files

In the `out/` folder:

| File | Typical size | Use |
|---|---|---|
| `klipper.elf` | ~400 KB | ELF binary with symbols (debug) |
| `klipper.bin` | ~70 KB | Raw binary (for direct flashing via rp2040load) |
| `klipper.hex` | ~200 KB | Intel HEX (other flashing tools) |
| **`klipper.uf2`** | **~140 KB** | **UF2 format for USB-copy flashing** |

**The file we care about:** `out/klipper.uf2`.

We rename it to `btteddy.uf2` for clarity in our workflow:

```bash
cp out/klipper.uf2 ~/btteddy.uf2
ls -lh ~/btteddy.uf2
# -rw-r--r-- 1 user user 140K Apr 22 10:43 /home/user/btteddy.uf2
```

### 4.3 UF2 file validation

A valid UF2 always starts with the `UF2\n` magic number (bytes `55 46 32 0A`).

```bash
od -t x1 ~/btteddy.uf2 | head -1
```

Expected output:

```
0000000  55 46 32 0a 57 51 5d 9e 00 20 00 00 00 00 00 00
```

The first 4 bytes `55 46 32 0a` confirm a genuine UF2.

The header can also be inspected to verify the target family:

```bash
python3 << 'EOF'
with open('/home/user/btteddy.uf2', 'rb') as f:
    header = f.read(32)
magic0 = int.from_bytes(header[0:4], 'little')
magic1 = int.from_bytes(header[4:8], 'little')
family_id = int.from_bytes(header[28:32], 'little')
print(f"Magic0: {hex(magic0)}")       # Expected: 0x0a324655 (UF2\n little-endian)
print(f"Magic1: {hex(magic1)}")       # Expected: 0x9e5d5157
print(f"Family: {hex(family_id)}")    # Expected: 0xe48bff56 (RP2040)
EOF
```

The `family_id = 0xe48bff56` is the official RP2040 marker in the UF2 spec. If the value differs, the firmware will not target the right microcontroller.

---

## 5. Flashing the Eddy on the Nebula

### 5.1 Transferring to the Nebula

As with `c_helper.so`, the codespace cannot reach the local network directly. Two methods:

**Method A — Download then SCP:**

1. In VS Code's codespace file explorer: right-click on `btteddy.uf2` → **Download**.
2. From Windows PowerShell:
   ```powershell
   scp C:\Users\<user>\Downloads\btteddy.uf2 `
       root@<NEBULA_IP>:/usr/data/E5M_CK/btteddy.uf2
   ```

**Method B — GitHub Raw (used by `install.sh`):**

1. Upload `btteddy.uf2` to the `christianKEL/E5M-CK` GitHub repository.
2. From the Nebula:
   ```bash
   wget --no-check-certificate \
     https://raw.githubusercontent.com/christianKEL/E5M-CK/main/btteddy.uf2 \
     -O /usr/data/E5M_CK/btteddy.uf2
   ```

### 5.2 Putting the Eddy into BOOT mode

To flash the RP2040, it must be put into BOOTSEL mode:

1. **Unplug** the Eddy from the Nebula's USB port.
2. **Hold down** the BOOT button (small tactile button next to the USB port on the Eddy).
3. **Plug** the Eddy into the Nebula while still holding BOOT.
4. **Wait 3 seconds** before releasing BOOT.

### 5.3 Verifying BOOT mode

On the Nebula:

```bash
lsusb | grep "2e8a:0003"
```

If you see:

```
Bus 001 Device 005: ID 2e8a:0003 Raspberry Pi RP2 Boot
```

The RP2040 is in BOOT mode. VID `2e8a` is Raspberry Pi, PID `0003` is the RP2040 bootloader.

You can also verify the mount:

```bash
mount | grep sda
```

Expected:

```
/dev/sda1 on /tmp/udisk/sda1 type vfat (rw,relatime,fmask=0022,...)
```

In BOOT mode, the RP2040 exposes a FAT16 disk containing:
- `INDEX.HTM` — link to Raspberry Pi docs.
- `INFO_UF2.TXT` — bootloader info.

### 5.4 Flashing

Copy the firmware onto the USB disk:

```bash
cp /usr/data/E5M_CK/btteddy.uf2 /tmp/udisk/sda1/
sync
```

**What happens:**

1. The file is written to the RP2040's FAT16 disk.
2. The RP2040 bootloader detects the `.uf2`, verifies the magic number and family_id.
3. It copies the firmware into the external SPI flash.
4. It **reboots** the RP2040 automatically in application mode.

Result: the USB disk disappears and the RP2040 re-enumerates as a CDC-ACM device (USB serial).

### 5.5 Flash validation

After ~5 seconds:

```bash
ls /dev/serial/by-id/
```

Expected:

```
usb-Klipper_rp2040_50445059303E9B1C-if00
```

The `Klipper_rp2040_` prefix confirms the Klipper firmware is running. The suffix (`50445059303E9B1C` in the example) is the unique RP2040 serial number — it **varies per Eddy unit**.

### 5.6 Common errors

**The Eddy does not enter BOOT mode:**
- Make sure you hold the BOOT button **before** plugging in, and release after.
- Try a different USB cable (some cables are "charge only" without data).
- Try another USB port on the Nebula.

**The Eddy is in BOOT mode but flashing fails:**
```
cp: write error: No space left on device
```
- The RP2040 bootloader only accepts `.uf2` files. Make sure you're copying `btteddy.uf2`, not `klipper.bin` or `.elf`.

**After flashing, no `/dev/serial/by-id/usb-Klipper_rp2040_...`:**
- The firmware was flashed but does not boot. Try flashing again.
- If it persists, try another Flash chip configuration (`W25Q080 with CLKDIV 2`).
- Check kernel messages: `dmesg | tail -30`.

**After flashing, a serial port appears but Klipper can't talk to it:**
- The firmware is flashed but incompatible with the host. Rebuild making sure **the Klipper commit in the codespace matches** the one on the Nebula.

---

## 6. Klipper host-side configuration

Once the firmware is flashed and the serial port is detected, Klipper must be configured to talk to the Eddy.

Create `/usr/data/printer_data/config/eddy.cfg`:

```ini
[mcu eddy]
serial: /dev/serial/by-id/usb-Klipper_rp2040_50445059303E9B1C-if00

[temperature_sensor btt_eddy_mcu]
sensor_type: temperature_mcu
sensor_mcu: eddy
min_temp: 10
max_temp: 100

[probe_eddy_current btt_eddy]
sensor_type: ldc1612
descend_z: 3.0
i2c_mcu: eddy
i2c_bus: i2c0f
x_offset: 38
y_offset: 6

[temperature_probe btt_eddy]
sensor_type: Generic 3950
sensor_pin: eddy:gpio26
horizontal_move_z: 2
```

**Replace** the `serial:` value with the one shown by `ls /dev/serial/by-id/` — the serial number is **unique** per Eddy.

**Important notes:**

- `i2c_bus: i2c0f` → RP2040 I2C bus used by the LDC1612 chip. Default value of the BTT Eddy firmware.
- `sensor_pin: eddy:gpio26` → RP2040 pin wired to the Eddy's onboard thermistor.
- `x_offset` / `y_offset` → physical offset between nozzle and Eddy sensor center. Measure on your machine.
- `descend_z: 3.0` → initial descent height used during calibration. Replaces the deprecated `z_offset` parameter in recent Klipper.

### 6.1 Include in `printer.cfg`

Add near the top of `printer.cfg`:

```
[include eddy.cfg]
```

And modify `[stepper_z]` to use the Eddy as a virtual endstop:

```
[stepper_z]
# ... other parameters ...
endstop_pin: probe:z_virtual_endstop
homing_retract_dist: 0
# Comment out the old line:
# position_endstop: 0
```

### 6.2 Restart and calibration

```bash
/etc/init.d/S55klipper_service restart
sleep 20
curl http://localhost:7125/printer/info | python3 -m json.tool | grep state
```

Once Klipper is `ready`, perform the Eddy calibrations in order:

1. `CAL_EDDY_DRIVE_CURRENT` → `LDC_CALIBRATE_DRIVE_CURRENT CHIP=btt_eddy` → `SAVE_CONFIG`.
2. `CAL_EDDY_MAPPING` → `PROBE_EDDY_CURRENT_CALIBRATE CHIP=btt_eddy` + TESTZ + ACCEPT → `SAVE_CONFIG`.
3. `CAL_BED_MESH` → `BED_MESH_CALIBRATE METHOD=rapid_scan` → `SAVE_CONFIG`.

---

## 7. Maintenance and updates

### 7.1 When should `btteddy.uf2` be rebuilt?

Rebuild and re-flash is required:

- After a major Klipper update on the Nebula (if protocol mismatches appear).
- If BTT ships a hardware revision of the Eddy that requires a different flash chip.
- To test a specific commit or a Klipper fork.

### 7.2 Full update procedure

In the codespace:

```bash
cd /workspaces/klipper
git pull
# or: git checkout <commit>

make clean
make menuconfig
# (ensure no option has changed — save)

make
cp out/klipper.uf2 ~/btteddy.uf2
```

Then flash as per Section 5.

### 7.3 Rollback

If the new version causes problems, revert to the previous `btteddy.uf2` and re-flash via the BOOT button.

Always keep a known-good copy of `btteddy.uf2` in `/usr/data/E5M_CK/` on the Nebula and in another safe location.

---

## 8. Recap — minimal commands

On a blank Ubuntu GitHub codespace:

```bash
# Prerequisites
sudo apt update
sudo apt install -y gcc-arm-none-eabi build-essential

# Klipper source (if not already there)
git clone https://github.com/Klipper3d/klipper.git /workspaces/klipper
cd /workspaces/klipper

# Configuration
cat > .config << 'EOF'
CONFIG_MACH_RP2040=y
CONFIG_MCU="rp2040"
CONFIG_RP2040_HAVE_BOOTLOADER=n
CONFIG_RP2040_FLASH_GENERIC_03H=y
CONFIG_RP2040_FLASH_CLKDIV=4
CONFIG_USBSERIAL=y
CONFIG_CLOCK_FREQ=12000000
CONFIG_USB_VENDOR_ID=0x1d50
CONFIG_USB_DEVICE_ID=0x614e
EOF

# Build
make clean
make

# The firmware is at out/klipper.uf2
cp out/klipper.uf2 ~/btteddy.uf2
ls -lh ~/btteddy.uf2
```

Then download `~/btteddy.uf2` via the VS Code file explorer, flash as per Section 5.

---

## 9. Additional notes

### 9.1 Difference vs. the official BTT firmware

The official `bigtreetech/Eddy` repository ships pre-built `.uf2` files in a `firmware/` folder. These files are identical to what we build here, **up to the Klipper version**.

If the official BTT firmware happens to match the exact Klipper version installed on the Nebula, it can be used as-is without rebuilding. But this is rare in practice: Klipper upstream moves fast, and BTT publishes firmware less frequently.

### 9.2 USB serial vs. CAN

Some newer Eddy products (Eddy Coil, Eddy NG) support CAN Bus. Our configuration is strictly **USB**. Don't mix up `menuconfig` options:

- **Eddy USB** → `CONFIG_USBSERIAL=y`.
- **Eddy Coil** (connected to a toolhead board via CAN) → `CONFIG_CAN=y` with a CAN-specific configuration.

For the BTT Eddy USB, **always** choose USB.

### 9.3 Flash chip — how to find the right one?

The flash chip is marked on the Eddy's PCB — a small SOIC-8 package near the RP2040. Common markings:

| Marking | menuconfig option |
|---|---|
| `W25Q080` or `25Q08xxx` | `W25Q080 with CLKDIV 2` |
| `W25Q16JV` | `W25Q080 with CLKDIV 2` (compatible) |
| Unclear marking | `GENERIC_03H with CLKDIV 4` (slower but universal) |

On current BTT Eddy USB units (2024–2026), `GENERIC_03H with CLKDIV 4` works in 100% of cases.

### 9.4 UF2 vs. BIN — why UF2?

The `.bin` format is a raw binary flashed via a tool like `rp2040load`, `openocd`, or `picotool`. It requires:
- Either access to the RP2040's SWD pins (on the BTT Eddy these pins exist but are not exposed on a header).
- Or a software tool that speaks the RP2040 bootloader protocol.

The `.uf2` format is designed for **copy-based flashing**: no tool required, just a `cp`. This is the ideal method on the Nebula, which has no `rp2040load` installed and can't easily install one (limited toolchain).

**`.uf2` = copy-based flashing. It is our only viable method on the Nebula.**

---

*Document written in April 2026 as part of the E5M-CK project.*

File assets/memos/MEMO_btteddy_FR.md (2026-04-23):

# MÉMOIRE TECHNIQUE — Génération de `btteddy.uf2`

## Firmware Klipper mainline pour BTT Eddy USB (RP2040)

**Auteur :** Christian KELHETTER
**Projet :** E5M-CK — https://github.com/christianKEL/E5M-CK
**Date :** Avril 2026

---

## 1. Contexte et problématique

### 1.1 Qu'est-ce que `btteddy.uf2` ?

`btteddy.uf2` est le **firmware Klipper** qui tourne sur le microcontrôleur RP2040 embarqué dans le BTT Eddy USB. C'est ce firmware qui :
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

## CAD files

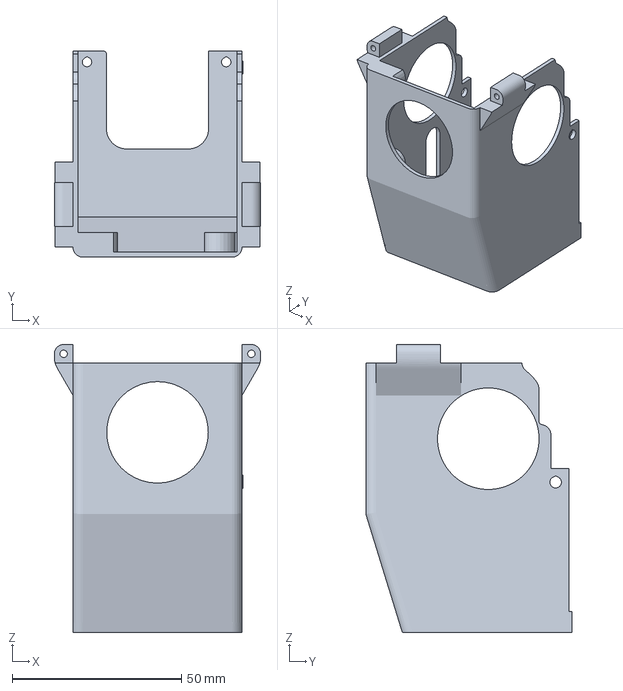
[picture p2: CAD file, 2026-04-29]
assets/prints/Toolhead E5M-CK.3mf
61.0 x 61.0 x 85.1 mm

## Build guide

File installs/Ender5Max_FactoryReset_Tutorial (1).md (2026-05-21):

# Ender 5 Max — Factory Reset Tutorial (for total beginners)

This guide walks you through installing a factory-reset script on your **stock Ender 5 Max** and then running it. No previous Linux experience needed — just copy and paste.

You'll do this **once**. After install, you'll be able to factory-reset the printer either with an SSH command or by plugging in a USB stick.

**Time needed:** about 10 minutes.

---

## ⚠️ Before you start — read this

This tutorial **only works if both of the following are true**:

1. **You have working access to the Nebula touchscreen** (it powers on, responds to taps, and you can navigate menus), **OR** root access has already been enabled on the printer at some earlier point.
2. **The printer is connected to the same WiFi network as your PC** (or via Ethernet to the same router).

**Why this matters:** Root SSH access on the Ender 5 Max can only be enabled from the screen (Settings → Root Account Information), and the SSH password is **only displayed on the screen** after you accept the EULA. There is no factory/default SSH password you can use without going through the screen at least once.

If your screen is broken, frozen, or otherwise unusable **and** root has never been enabled on the printer, **stop here** — the steps below won't work. You'd need to repair the screen, reflash firmware via USB, or use a pre-rooted firmware image first. Those topics are outside this tutorial.

---

## What you need

- A Windows PC (PowerShell is already built in)
- Your printer powered on and connected to the same WiFi as your PC
- A few minutes of patience

> 💡 *"SSH" just means "remote terminal". You'll type commands on your PC and they'll execute on the printer.*

---

## PART 1 — Prepare the printer

### Step 1: Enable root access on the printer

On the printer's touchscreen:

1. Tap the **gear icon** (Settings)
2. Tap **Root Account Information**
3. A long warning text appears. Scroll to the **bottom** of the text.
4. Check the box that says "I have read and accept..."
5. Tap **Next Step**
6. Wait about 30 seconds.
7. **Important** — the screen will now show you the **username** (`root`) and the **password** for SSH. Write them down or take a picture. Per Creality's official guide, "Enter 'Settings - Root Account Information', and accept the 'Warning', then you can get the root account and password of your printer." Creality has used different passwords across firmware versions (`creality_2023`, `creality_2024`, `Creality@2024_Wh_464`, and others) — the one your printer is showing right now is the *only* one you can trust.
8. Confirm the status shows **Root** (usually in yellow).

✅ Root access is now enabled. This is permanent — you only do it once.

### Step 2: Note your printer's IP address

**The easy way — from the screen:**

1. Tap **Settings**
2. Tap the **Network** tab
3. Write down the IP address shown (e.g. `192.168.1.42`)

**If the screen is not accessible** (but root SSH was previously enabled — see the warning at the top), use one of these two alternatives:

#### Alternative A — Look in your internet box / router

1. Open a web browser on your PC
2. Go to your router's admin page. Common addresses: `http://192.168.1.1`, `http://192.168.0.1`, `http://mafreebox.freebox.fr` (Freebox), `http://livebox` (Orange Livebox), `http://192.168.1.254` (SFR/Bouygues).
3. Log in (admin password is usually on a sticker on the box)
4. Find the **Connected devices** / **DHCP** / **Network map** section
5. Look for a device named something like **Creality**, **Nebula**, **F004**, or a device you don't recognize. Note its IP.

#### Alternative B — Scan the network from PowerShell

Open PowerShell (Win key → type `powershell` → Enter), then:

1. Find your subnet by running:
   ```
   ipconfig
   ```
   Look at the line **IPv4 Address** under your active connection (Wi-Fi or Ethernet). Example: `192.168.1.27`. The "subnet prefix" is the first three numbers — here, `192.168.1`.

2. Sweep the network and list everything found. Replace `192.168.1` below with **your** prefix:
   ```
   1..254 | ForEach-Object { Start-Job { param($i) Test-Connection -Count 1 -Quiet "192.168.1.$i" } -ArgumentList $_ } | Wait-Job | Remove-Job; arp -a
   ```
   This takes ~30 seconds. It pings every address on your network in parallel, then prints the ARP table.

3. In the output, look for unfamiliar IP addresses (your printer is the one you don't recognize). To verify which one is the printer, you can connect to it via SSH (next step) — if the password from the screen works, you found it.

> 💡 *If neither alternative works, you really do need screen access. There's no other reliable way.*

Keep your IP address handy — you'll need it in the next step.

---

## PART 2 — Connect to the printer with PowerShell

### Step 3: Open PowerShell on Windows

1. Press the **Windows key** on your keyboard
2. Type **powershell**
3. Press **Enter**

A dark window with light text opens. That's PowerShell.

### Step 4: Connect via SSH

In the PowerShell window, type the following (replace `192.168.1.42` with **your** printer's IP from Step 2):

```
ssh root@192.168.1.42
```

Press Enter.

**What happens the first time:**

1. **You may see a warning:**
   > The authenticity of host '192.168.1.42' can't be established... Are you sure you want to continue connecting (yes/no)?

   Type **yes** and press Enter. This only appears the first time.

2. **You'll be asked for a password:**
   > root@192.168.1.42's password:

   Type the password that was displayed on the printer screen in **Step 1**. ⚠️ **Nothing will appear on screen as you type — no dots, no asterisks. This is normal, not broken.** Press Enter when done.

   > 💡 *If you didn't write it down, go back to the printer screen: Settings → Root Account Information. The password is shown there.*

3. **Success looks like this** — the prompt changes to something like:
   ```
   [root@F004 ~]#
   ```
   That `#` at the end means you're in. 🎉

---

## PART 3 — Install the factory-reset script

You're now talking to the printer. Three commands to copy and paste, one at a time.

### Step 5: Move to the temporary folder

```
cd /tmp
```

Press Enter. Nothing visible happens — that's fine.

### Step 6: Download the two files from GitHub

Copy and paste **the whole block** below into PowerShell, then press Enter:

```
wget --no-check-certificate -O install_factory_reset.sh https://raw.githubusercontent.com/christianKEL/E5M-CK/main-v2/installs/install_factory_reset.sh
wget --no-check-certificate -O S58factoryreset https://raw.githubusercontent.com/christianKEL/E5M-CK/main-v2/system/etc/init.d/S58factoryreset
```

You should see two short downloads, each ending with something like:
```
'S58factoryreset' saved
```

### Step 7: Run the installer

```
sh install_factory_reset.sh < S58factoryreset
```

Press Enter. You should see several lines that look like:

```
[14:32:01] Reading new S58factoryreset from stdin...
[14:32:01] Received: 1234 bytes, md5=abc...
[14:32:01] Backed up original /etc/init.d/S58factoryreset -> /usr/data/backup/S58factoryreset.orig
[14:32:01] Installed: /etc/init.d/S58factoryreset (md5=abc...)
[14:32:01] Smoke test: usage output OK.
[14:32:01] Done.
```

✅ The factory-reset script is now installed on your printer.

> 💡 *If something goes wrong here, the script prints `ERROR: ...` and stops. Nothing is broken — read the message, fix the issue, and re-run.*

---

## PART 4 — Run a factory reset

You now have **two ways** to factory-reset the printer at any time.

### Method A — Right now, from SSH

Still in the SSH session, type:

```
/etc/init.d/S58factoryreset reset
```

Press Enter. The printer will erase its user data and reboot. Wait until you see the stock welcome screen.

> ⚠️ This wipes your WiFi config, any installed mods, custom Klipper configs, and gcode files. Make sure you really want to do this.

### Method B — Later, with a USB stick

This works even if SSH is broken or the printer is offline.

1. Take a USB stick and **format it as FAT32**
2. Create an **empty file named `factory_reset`** at the root (no file extension)
   - On Windows: right-click in the USB drive window → New → Text Document → name it `factory_reset` and delete the `.txt` extension
   - If Windows hides extensions: Explorer → View → check "File name extensions"
3. **Power off** the printer
4. **Plug the USB stick** into the front USB port
5. **Power on** the printer
6. The factory reset runs automatically during boot

The printer keeps your WiFi settings; everything else is wiped.

---

## When you're done

To exit SSH and close PowerShell:

```
exit
```

Press Enter. The connection closes. You can close the PowerShell window.

---

## Troubleshooting

**"`ssh` is not recognized as a command"**
Your Windows version is too old or OpenSSH isn't installed. Open Settings → Apps → Optional Features → "Add a feature" → search for **OpenSSH Client** → install. Then re-open PowerShell.

**"Connection refused" or it just hangs**
- Are your PC and printer on the same WiFi network?
- Is the IP from Step 2 still correct? (Your router may have changed it — check the screen again.)
- Did you complete Step 1 (Enable Root Access) on the printer?

**"Permission denied" after typing the password**
- Caps Lock off?
- Did you type the password exactly? (The `@`, `_` and digits matter.)
- Try the other password (`creality_2023` if you tried `Creality@2024_Wh_464`, or vice versa).

**"Host key verification failed" / "Remote host identification has changed"**
This happens if you reinstalled firmware. Run this on your PC (replace IP):
```
ssh-keygen -R 192.168.1.42
```
Then connect again.

**`wget` says SSL/certificate error**
Use `curl` instead:
```
curl -kL -o install_factory_reset.sh https://raw.githubusercontent.com/christianKEL/E5M-CK/main-v2/installs/install_factory_reset.sh
curl -kL -o S58factoryreset https://raw.githubusercontent.com/christianKEL/E5M-CK/main-v2/system/etc/init.d/S58factoryreset
```

**`sh install_factory_reset.sh` says "md5 mismatch" or "size mismatch"**
The script was downloaded incompletely. Re-run the `wget` commands from Step 6, then try again.

---

*Tutorial built for the E5M-CK install_factory_reset.sh deployer — christianKEL/E5M-CK on GitHub.*

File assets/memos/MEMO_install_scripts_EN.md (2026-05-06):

# MEMO — E5M-CK install scripts (architecture, generation, usage)

> **Scope** — This memo documents every install script in `installs/` of the E5M-CK repository: how each one was designed, what problem it solves, when to run it, what it modifies, and how to debug it. Audience: developers maintaining or forking the project, including the original author six months from now.

---

## Table of contents

1. [Project context](#1-project-context)
2. [Shared conventions](#2-shared-conventions)
3. [Hosted binaries](#3-hosted-binaries)
4. [Script-by-script reference](#4-script-by-script-reference)
5. [Recommended install order](#5-recommended-install-order)
6. [Update workflow](#6-update-workflow)
7. [Debugging cheat sheet](#7-debugging-cheat-sheet)

---

## 1. Project context

E5M-CK is a stack rebuild for the **Creality Ender 5 Max** with **Nebula Pad** (touchscreen control unit). The goal is to replace the stock Creality firmware/Helper-Script setup with a fully autonomous, reproducible install of:

- **Klipper mainline** (instead of Creality's fork)
- **Moonraker** (with working Update Manager)
- **Fluidd** (web UI)
- **GuppyScreen** (touch UI by ballaswag)
- **BTT Eddy USB** (eddy current probe)

The Nebula Pad runs **Buildroot Linux** on an **Ingenic X2000 SoC** (MIPS XBurst II V2). All scripts target this platform exclusively.

### Hardware identifiers

- **SoC** — Ingenic X2000 (`uname -m` returns `mips`)
- **Mainboard MCU** — GD32F303RET6, board ID `CR4NS200323C10`
- **Nozzle MCU** — GD32F303CBT6, board ID `CR-NOZZLE_V21`
- **Touchscreen** — 480×544 px, accessed via `/sys/class/graphics/fb0`
- **Stock loader** — `/lib/ld-2.29.so` (Creality 1.3.x firmware)

### Repository layout

```
E5M-CK/
├── installs/                 # 12 install scripts (subject of this memo)
├── configs/                  # Configuration files deployed to the printer
│   ├── moonraker.conf
│   ├── guppyconfig.json
│   ├── backup-fluidd-v1.36.4-fluidd.json
│   └── cfg/                  # Klipper *.cfg files
├── files/                    # Binary blobs hosted in the repo
│   ├── c_helper.so
│   ├── btteddy.uf2
│   ├── moonraker-env.tar.gz
│   └── e5m_ck_logo.jpg
└── assets/memos/             # Technical documentation (FR + EN)
```

---

## 2. Shared conventions

Every install script follows the same conventions. Once you've read one, you've read them all.

### 2.1 Execution model

Scripts run **on the printer** over SSH. The standard one-liner is:

```sh
wget --no-check-certificate \
    https://raw.githubusercontent.com/christianKEL/E5M-CK/main/installs/install_<name>.sh \
    -O /tmp/install_<name>.sh && sh /tmp/install_<name>.sh
```

This pattern was chosen because:

- The Nebula Pad has very limited tooling (no `git` initially, busybox-only utilities, no `bash`).
- The user can copy a single line to install or update anything.
- `wget` and `sh` are always present.

### 2.2 Visual identity

Every script begins with a banner:

```
    ███████╗███████╗███╗   ███╗       ██████╗██╗  ██╗
    ██╔════╝██╔════╝████╗ ████║      ██╔════╝██║ ██╔╝
    █████╗  ███████╗██╔████╔██║█████╗██║     █████╔╝
    ██╔══╝  ╚════██║██║╚██╔╝██║╚════╝██║     ██╔═██╗
    ███████╗███████║██║ ╚═╝ ██║      ╚██████╗██║  ██╗
    ╚══════╝╚══════╝╚═╝     ╚═╝       ╚═════╝╚═╝  ╚═╝

              install_<name>.sh
        <one-line description>

                    ▓▓ CR*ALITY S*CKS ▓▓

         github.com/christianKEL/E5M-CK
```

A red/white/black ANSI palette is applied throughout. The "CR*ALITY S*CKS" tag is intentional — it signals to the user that this is a third-party, opinionated alternative to Creality's stock setup.

### 2.3 Logging primitives

All scripts share five log helpers:

| Helper | Symbol | Purpose |
|---|---|---|
| `log_info "msg"` | `i` | Informational |
| `log_ok "msg"` | `✓` | Step succeeded |
| `log_warn "msg"` | `!` | Non-fatal anomaly |
| `log_error "msg"` | `✗` | Fatal error (caller usually `exit 1`) |
| `log_action "msg"` | `>` | Sub-step / detail |

And one section header:

| Helper | Output |
|---|---|
| `log_step "N" "Title"` | A boxed banner around the step number and title |

Every log line is prefixed with the current `HH:MM:SS` time, which is essential when debugging from a terminal scrollback.

### 2.4 Common patterns

**`die()`** — fatal-error helper that calls `log_error` then `exit 1`:

```sh
die() {
    log_error "$1"
    exit 1
}
```

**`confirm()`** — interactive y/N prompt that defaults to "no":

```sh
confirm() {
    printf "  > $1 [y/N] "
    read CONFIRM
    case "$CONFIRM" in
        y|Y|yes|YES) return 0 ;;
        *) return 1 ;;
    esac
}
```

**`find_python()`** — locate the best Python 3 interpreter available, in priority order: `/opt/bin/python3` (Entware), `/usr/bin/python3` (system), `/usr/share/klippy-env/bin/python` (Klipper venv), `/usr/data/moonraker/moonraker-env/bin/python` (Moonraker venv).

### 2.5 Idempotence

Most scripts support being re-run safely. The two main patterns are:

- **Flag files** — A marker like `/usr/data/<thing>/.e5m_ck_installed` plus a version file `/usr/data/<thing>/.e5m_ck_version`. On re-run, the script detects the existing install and switches to UPDATE mode.
- **Conditional operations** — Each step checks whether its target state is already reached (`if [ ! -f ... ]`, `if pgrep ... >/dev/null`) before acting.

When idempotence cannot be guaranteed (e.g. `install_factory_reset.sh`), the script declares its destructive nature in the disclaimer and requires `y` confirmation.

### 2.6 Backups

Every script that modifies system files creates a timestamped or named backup first:

| Path | Created by |
|---|---|
| `/usr/data/E5M_CK/<file>.bak.<date>` | Most install scripts |
| `/usr/data/guppyify-backup/` | `install_guppyscreen.sh` |
| `/usr/data/logo_originals/` | `install_personalization.sh` |
| `/usr/data/klipper/klippy/configfile.py.bak.before_e5m_ck` | `install_klipper_patches.sh` |
| `/etc/init.d/S56moonraker_service.before_E5M_CK` | `install_moonraker.sh` |
| `/etc/init.d/S50nginx.bak` | `install_nginx.sh` |

Backups are designed to allow manual rollback if the script fails partway or if the user wants to revert.

### 2.7 Hosted binaries

A few binaries cannot be reasonably regenerated on the printer (no compiler toolchain, no Python build environment for some packages). They are hosted in `files/` of the repo with documented MD5 hashes for integrity verification. See section 3.

---

## 3. Hosted binaries

The repo hosts four binary files that the install scripts download. Each is documented with its origin and integrity hash where applicable.

| File | Size | Origin | Used by |
|---|---|---|---|
| `c_helper.so` | ~150 KB | Compiled MIPS XBurst2 helper from Klipper repo (extracted from Helper-Script) | `install_klipper.sh` |
| `btteddy.uf2` | ~70 KB | BTT firmware for the Eddy USB probe | `install_eddy.sh` |
| `moonraker-env.tar.gz` | ~16 MB | Pre-built Python virtual environment for Moonraker (extracted from Helper-Script's working install, validated via `pip list`) | `install_moonraker.sh` |
| `e5m_ck_logo.jpg` | varies | Custom boot logo image | `install_personalization.sh` |

The rationale for hosting these in the repo (rather than pulling them from upstream sources) is **autonomy** — the project should not break if Helper-Script disappears, if BTT changes URLs, or if upstream venv builds become unavailable. Hosted binaries are pinned and reproducible.

See `assets/memos/MEMO_c_helper_FR.md` and `MEMO_moonraker_venv_FR.md` for the full traceability of those two binaries.

---

## 4. Script-by-script reference

### 4.1 `install_factory_reset.sh`

**Purpose** — Reset the printer's filesystem state by triggering Creality's stock factory-reset mechanism (a USB key with a specific marker file).

**Generated because** — At the start of the project, we needed a clean baseline before installing anything. Re-runnable factory resets are useful when a user wants to scrap an install and start over without re-flashing the SD card.

**Pre-conditions** — None (works on any Nebula Pad state).

**Post-conditions** — Stock Creality firmware restored. `/usr/data/` is **preserved** (this is by Creality's design — they only reset `/etc/init.d/`, `/usr/bin/`, etc.).

**Steps** —
1. Pre-checks (network, disk).
2. Deploy the factory-reset trigger script `S58factoryreset` to `/etc/init.d/`.
3. Print instructions: insert a USB key with a file named `factory_reset` (no extension) at the root, then power-cycle the printer.

**Idempotent** — Yes. Re-running just re-deploys the trigger script.

**Notes** — The factory reset itself is performed by Creality's stock loader on next boot; this script only prepares the trigger. If the trigger script is already present, it is overwritten.

---

### 4.2 `install_entware.sh`

**Purpose** — Install Entware (an OpenWrt-derived package manager) at `/opt/`. Provides `python3`, `git`, `curl`, `wget` (modern), `nano`, `htop`, and other tools missing from the Buildroot rootfs.

**Generated because** — The Nebula Pad's Buildroot is too minimal for a Klipper/Moonraker install: no `git`, no real `python3`, no `pip`. Entware solves this without modifying the read-only rootfs (it lives entirely in `/opt/`, which is on `/usr/data/`).

**Pre-conditions** —
- Network connectivity.
- `/opt/` and `/overlay/` are mounted (default on Nebula Pad).
- Architecture detected as `mips` with `nan2008` ABI flags.

**Post-conditions** — Entware fully installed. `~70 packages` available. `/etc/profile.d/entware.sh` ensures `/opt/bin` and `/opt/sbin` are in `$PATH` after a re-login.

**Steps** —
1. Pre-checks (architecture, mountpoints, network).
2. Download Entware bootstrap script (`mipselsf-k3.4` variant, NOT `armv7sf-k3.2`).
3. Run bootstrap, which extracts Entware to `/opt/` and registers `S52entware` in init.d.
4. Install baseline packages: `python3 git curl wget-ssl nano htop`.
5. Verify by running `python3 --version` and `git --version`.

**Idempotent** — Partially. If `/opt/bin/opkg` is present, the script skips the bootstrap and only verifies/upgrades packages.

**Common failure modes** —
- Network timeout downloading bootstrap — retry.
- Architecture mismatch — script aborts with explicit message; the user must verify `uname -m` returns `mips`.
- Disk full — Entware needs ~50 MB free in `/usr/data/`.

---

### 4.3 `install_klipper.sh`

**Purpose** — Install Klipper mainline at `/usr/data/klipper/`, reusing the Creality stock Python venv at `/usr/share/klippy-env/`.

**Generated because** — The Creality stock firmware ships an old Klipper fork with custom patches. We want mainline Klipper for two reasons: bug fixes, and a clean Update Manager workflow via Moonraker.

**Pre-conditions** —
- Entware installed (for `git`).
- Stock Klipper venv intact at `/usr/share/klippy-env/` (Python 3.8.2 with `venv` module).
- Network OK.

**Post-conditions** —
- Klipper cloned at `/usr/data/klipper/` (master branch).
- `/etc/init.d/S55klipper_service` patched to point at the new path (`PY_SCRIPT=/usr/data/klipper/klippy/klippy.py`).
- The original copy_config call inside S55klipper_service is **disabled** (it would otherwise overwrite our printer.cfg at every boot).
- `klippy/chelper/c_helper.so` deployed (MIPS XBurst2 binary).
- `.git/info/exclude` populated to ignore future GuppyScreen/shell-command additions.

**Steps** —
1. Pre-checks.
2. Stop running Klipper service.
3. Backup `/etc/init.d/S55klipper_service`.
4. Clone Klipper from `https://github.com/Klipper3d/klipper.git` to `/usr/data/klipper/`.
5. Download `c_helper.so` from the repo's `files/` directory and deploy it.
6. Patch `S55klipper_service`: change `PY_SCRIPT` path, comment out `copy_config`.
7. Add Klipper-related entries to `.git/info/exclude`.
8. Restart Klipper service, verify `state: ready`.

**Idempotent** — Mostly yes. If `/usr/data/klipper/` exists, the script does a `git pull` instead of clone (UPDATE mode).

**Common failure modes** —
- `c_helper.so` 404 from GitHub — check `files/c_helper.so` exists in the repo.
- Klipper config errors after restart — caused by old printer.cfg referencing config sections that don't exist in mainline. Fix the config (see `install_configs.sh`).

---

### 4.4 `install_gcode_shellcommand.sh`

**Purpose** — Install the `gcode_shell_command.py` extension to Klipper's `extras/`, enabling shell command execution from G-code (used by GuppyScreen for things like input shaper calibration).

**Generated because** — Several GuppyScreen features and macros require running shell commands from G-code. The standard module is hosted in our repo for reproducibility (it comes from Helper-Script originally, but we own a copy).

**Pre-conditions** — Klipper installed at `/usr/data/klipper/`.

**Post-conditions** — `/usr/data/klipper/klippy/extras/gcode_shell_command.py` deployed. `.git/info/exclude` updated to keep it from polluting `git status`.

**Steps** —
1. Download `gcode_shell_command.py` from the repo's `files/` directory.
2. Copy to `klippy/extras/`.
3. Update `.git/info/exclude` if not already present.
4. Restart Klipper, verify `state: ready` (the new module shouldn't break anything if printer.cfg doesn't reference it yet).

**Idempotent** — Yes. Always re-deploys the file.

---

### 4.5 `install_klipper_patches.sh`

**Purpose** — Apply surgical patches to the local Klipper clone to suppress harmless warnings that come from the Creality MCU stack.

**Generated because** — The Creality MCU firmware (frozen July 2023) lacks features added to Klipper later, notably `STEPPER_STEP_BOTH_EDGE`. Klipper warns about this on every connection, cluttering Fluidd's UI. The warning is purely informational (we compensate via `step_pulse_duration` in printer.cfg).

**Pre-conditions** — Klipper installed at `/usr/data/klipper/` with git history.

**Post-conditions** —
- `klippy/configfile.py` patched: `deprecate_mcu_code()` returns early when `feature == 'STEPPER_STEP_BOTH_EDGE'`.
- Patch committed locally to the Klipper git repo (so `git status` stays clean).
- Backup at `klippy/configfile.py.bak.before_e5m_ck`.

**Steps** —
1. Pre-checks (Klipper dir, configfile.py, python3, service).
2. Backup `configfile.py` before patching (preserved if already exists).
3. Apply patch via `python3` text replacement. Three outcomes possible:
   - `APPLIED` — first run, success.
   - `ALREADY_PATCHED` — script re-run, no-op.
   - `PATTERN_NOT_FOUND` — Klipper version diverged, abort.
4. Commit the change locally (skipped if no diff vs HEAD).
5. Restart Klipper, wait until `state: ready`.
6. Verify the `STEPPER_STEP_BOTH_EDGE` string no longer appears in `printer/info` warnings.

**Idempotent** — Yes (explicitly designed for re-run).

**Notes** —
- After this script, the Klipper version reports as `vX.Y.Z-NNN-gHASH-dirty` where the commit count `NNN` is one higher than upstream, and the hash is your local commit. This is expected and documented in `MEMO_klipper_dirty_FR.md`.
- A future `git pull` that touches `configfile.py:533` will require manual conflict resolution. The function has been stable for years; risk is low.
- See [Issue #1] on the GitHub repo for the full rationale and the proper fix (reflashing MCUs with mainline firmware) which is out of scope for now.

---

### 4.6 `install_moonraker.sh`

**Purpose** — Install Moonraker at `/usr/data/moonraker/` with a fully working Update Manager.

**Generated because** — Moonraker is required for Fluidd, GuppyScreen, and remote management. Compiling the Python venv on the Nebula Pad is impractical (no GCC, slow CPU, missing build deps). We host a pre-built venv in the repo.

**Pre-conditions** —
- Klipper running.
- Network OK.
- `~50 MB free` for the venv extraction.

**Post-conditions** —
- Moonraker cloned at `/usr/data/moonraker/` from `https://github.com/Arksine/moonraker.git` (so Update Manager can `git pull`).
- Pre-built venv extracted at `/usr/data/moonraker/moonraker-env/` from `files/moonraker-env.tar.gz`.
- pip upgrade applied for `paho-mqtt==2.1.0`, `inotify-simple==2.0.1`, `jinja2==3.1.6` (with `--no-deps` for jinja2 to keep MarkupSafe 2.1.1).
- `/etc/init.d/S56moonraker_service` deployed.
- `moonraker.conf` deployed at `/usr/data/printer_data/config/` with `provider: none` (Buildroot has no supervisord).

**Modes** —
- **FULL** — first install. Downloads the venv tarball (16 MB), extracts, clones Moonraker code, deploys conf and init script.
- **UPDATE** — subsequent runs. Just `git pull` the Moonraker code; the venv is reused.

Detected via `/usr/data/moonraker/.e5m_ck_installed` flag.

**Steps (FULL mode)** —
1. Pre-checks.
2. Stop Moonraker if running.
3. Download `moonraker-env.tar.gz` to `/usr/data/.tmp_install/`. Verify MD5 (hardcoded) and size.
4. Clone Moonraker code from Arksine/moonraker.git.
5. Extract venv tarball into `/usr/data/moonraker/`.
6. Apply pip upgrades (with the right flags to avoid breaking existing deps).
7. Deploy `moonraker.conf` from the repo.
8. Deploy `S56moonraker_service` (backup the original first).
9. Start Moonraker, wait until `klippy_connected: true`.
10. Mark `.e5m_ck_installed` flag.

**Steps (UPDATE mode)** — Same except steps 3, 5, 6, 7, 8 are skipped or replaced by `git pull origin master`.

**Idempotent** — Yes via the flag/UPDATE mode.

**Common failure modes** —
- MD5 mismatch on tarball — file corruption during download, retry. If persistent, re-host the tarball.
- pip upgrade fails (no network in venv) — verify Entware's curl/openssl are installed.
- `klippy_connected` stays false — usually a Klipper config error. Run `tail -50 /usr/data/printer_data/logs/klippy.log` to see the cause.

---

### 4.7 `install_nginx.sh`

**Purpose** — Install nginx (from Entware) and configure it as a reverse proxy in front of Fluidd (port 4408) and Mainsail (port 4409, reserved for future use).

**Generated because** — Moonraker's built-in HTTP server is enough for development but not for serving a frontend like Fluidd. Nginx provides proper static file serving, gzip compression, and websocket proxying.

**Pre-conditions** —
- Entware installed (for `nginx-ssl`).
- Moonraker running on port 7125.

**Post-conditions** —
- nginx 1.26.3 installed via `opkg install nginx-ssl`.
- `/usr/data/nginx/nginx.conf` generated with explicit IPv4-only listen directives (Buildroot has no IPv6).
- `/etc/init.d/S50nginx` deployed (custom version with proper PID handling).
- nginx running, listening on 4408 and 4409.

**Steps** —
1. Pre-checks (Entware, Moonraker).
2. Backup any pre-existing `/etc/init.d/S50nginx` to `S50nginx.bak`.
3. `opkg install nginx-ssl`.
4. Generate `/usr/data/nginx/nginx.conf` via heredoc. The conf includes:
   - `listen 4408;` and `listen 4409;` (IPv4 only)
   - Locations for `/`, `/websocket`, `/printer/`, `/api/`, `/access/`, `/server/`, etc.
   - Static file serving from `/usr/data/fluidd/` and `/usr/data/mainsail/`.
5. Generate `/etc/init.d/S50nginx` (start/stop/restart/reload/status with `start-stop-daemon`).
6. Start nginx, verify ports 4408/4409 listening.

**Idempotent** — Yes. Re-running re-installs nginx (opkg handles "already installed") and overwrites the conf and init script.

**Common failure modes** —
- Port 4408 already used — kill the process holding it before retrying.
- IPv6 binding errors — the conf is explicitly IPv4 only; if errors persist, check `cat /etc/nginx/nginx.conf` includes from elsewhere.

---

### 4.8 `install_fluidd.sh`

**Purpose** — Install Fluidd (web UI) at `/usr/data/fluidd/`.

**Generated because** — Fluidd is the recommended web UI for Klipper/Moonraker. It's a static site (Vue.js single-page app) so install is just download + extract.

**Pre-conditions** — nginx installed and configured.

**Post-conditions** — `/usr/data/fluidd/` populated with the Fluidd build. Accessible at `http://<printer-ip>:4408/`.

**Steps** —
1. Download latest Fluidd zip from `https://github.com/fluidd-core/fluidd/releases/latest/download/fluidd.zip`.
2. Extract to `/usr/data/fluidd/`.
3. Verify nginx serves the index.html.

**Idempotent** — Yes. Always replaces the directory.

**Notes** — Update Manager handles future updates from Fluidd's GitHub releases (this script is only for the initial install).

---

### 4.9 `install_configs.sh`

**Purpose** — Deploy the E5M-CK Klipper configuration files to `/usr/data/printer_data/config/`.

**Generated because** — Klipper requires `printer.cfg` and the included `*.cfg` files (`eddy.cfg`, `homing.cfg`, `macros_calibration.cfg`, `macros_E5M_CK.cfg`, `gcode_macro.cfg`, `guppy_cmd.cfg`). They are versioned in the repo's `configs/cfg/` directory.

**Pre-conditions** — Klipper running, `/usr/data/printer_data/config/` exists.

**Post-conditions** — All `*.cfg` files from `configs/cfg/` deployed.

**Steps** —
1. Auto-discover available `.cfg` files via the GitHub Contents API: `https://api.github.com/repos/christianKEL/E5M-CK/contents/configs/cfg`.
2. For each `.cfg` returned, download via the raw URL and write to `/usr/data/printer_data/config/`.
3. Restart Klipper, verify `state: ready`.

**Idempotent** — Yes. Always overwrites; no backup is created (the user explicitly requested no backup files).

**Common failure modes** —
- GitHub API rate limit (60 requests/hour unauthenticated) — wait and retry.
- Klipper fails to start after deploy — check the logs; usually a typo in a recently-edited cfg.

---

### 4.10 `install_eddy.sh`

**Purpose** — Flash the BTT Eddy USB probe with the firmware shipped in `files/btteddy.uf2`.

**Generated because** — The BTT Eddy ships in DFU mode and needs a Klipper-compatible firmware flashed before use. The firmware is hosted in the repo for reproducibility.

**Pre-conditions** —
- BTT Eddy connected via USB to the Nebula Pad.
- The user has prepared a USB key with a single FAT32 partition (no specific files; Creality auto-mounts it at `/tmp/udisk/sdaN`).

**Post-conditions** —
- Firmware flashed to the Eddy.
- After Klipper restart, `mcu eddy` shows up as connected via `/dev/serial/by-id/usb-Klipper_rp2040_*`.

**Steps** —
1. Pre-checks (network, BTT Eddy auto-mounted).
2. Detect the USB mount path via `mount | grep -oE '/tmp/udisk/sd[a-z][0-9]*'`.
3. Verify it's a real Eddy by checking for `INFO_UF2.TXT` at the mount root (BTT bootloader signature).
4. Download `btteddy.uf2` from the repo's `files/` directory (size + MD5 verified).
5. Copy `btteddy.uf2` to the USB mount root. The bootloader auto-flashes and reboots.
6. Wait for the new serial port to appear (typically 5-10s).
7. Restart Klipper, verify `mcu eddy` is connected.

**Idempotent** — Yes (re-flashing the same firmware is a no-op functionally).

**Common failure modes** —
- USB key not recognized — check the FAT32 partitioning, try a different key.
- `INFO_UF2.TXT` not found — wrong mount, or the Eddy is in normal-mode (not DFU). Reset by holding the boot button while plugging USB.
- Klipper still doesn't see the Eddy — check `printer.cfg` references `usb-Klipper_rp2040_*` matching the actual serial-by-id (may differ between Eddy units).

---

### 4.11 `install_guppyscreen.sh` (v2)

**Purpose** — Install GuppyScreen (LVGL-based touch UI by ballaswag) at `/usr/data/guppyscreen/`. Replaces Creality's stock display server.

**Generated because** — Creality's stock UI is closed-source and tightly coupled to their cloud services. GuppyScreen is open-source, reads directly from Moonraker, and provides a clean Klipper-native experience on the touchscreen.

**Pre-conditions** —
- Klipper + Moonraker running.
- Touchscreen working (any UI displayed on it).
- ld-2.29.so present (Creality 1.3.x firmware).

**Post-conditions** —
- GuppyScreen binary running, controlling `/dev/fb0`.
- Klipper extras populated (linked symlinks for guppy modules).
- `/etc/init.d/S99guppyscreen` deployed.
- `/etc/init.d/S50dropbear` replaced with GuppyScreen's modified version (starts SSH before display).
- Optionally: Creality services disabled (`master-server`, `app-server`, `display-server`, `Monitor`, `audio-server`, `upgrade-server`, `log_main`, `cx_ai_middleware`, `webrtc`).

**Modes** —
- **FULL INSTALL** — no existing install detected. Full sequence including service replacement and Creality disable prompt.
- **UPDATE** — `.e5m_ck_installed` flag found. Compares installed version vs latest GitHub release. If newer available, downloads + extracts only. Skips service install and Creality disable (already done).

**Auto-detection** — Screen size is detected via `cat /sys/class/graphics/fb0/virtual_size`. If both dimensions are <800 px (the case for the 480×544 Nebula Pad), the script downloads `guppyscreen-smallscreen.tar.gz`. Otherwise `guppyscreen.tar.gz`.

**Steps (FULL mode)** —
1. Pre-checks.
2. Detect mode + check latest version via GitHub API.
3. Stop GuppyScreen if running (Creality display still up — keeps screen alive).
4. Download tarball, validate.
5. Extract to `/usr/data/`.
6. Install system symlinks: `/lib/libeinfo.so.1` and `/lib/librc.so.1` → respawn-daemon libs.
7. Install Klipper extras (linked symlinks for `guppy_module_loader.py`, `guppy_config_helper.py`, `tmcstatus.py`; hard copy for `calibrate_shaper_config.py`).
8. Deploy GuppyScreen config files to `/usr/data/printer_data/config/GuppyScreen/`.
9. Backup originals, install `S99guppyscreen` and replace `S50dropbear`.
10. Restart Klipper to load the new extras.
11. Start GuppyScreen, verify it's running using `guppy_pid()` helper (waits up to 20s).
12. Prompt user: "Disable all Creality services?" — see below.
13. Mark `.e5m_ck_installed` and `.e5m_ck_version` flags.
14. Cleanup temp files.

**Creality disable prompt (step 12)** — Two paths:
- **YES** — Kill 9 Creality processes (`master-server`, `app-server`, `display-server`, `Monitor`, `audio-server`, `upgrade-server`, `log_main`, `cx_ai_middleware`, `webrtc`). Remove `/etc/init.d/S99start_app`. Network daemons (`wpa_supplicant`, `ifplugd`, `dropbear`, `mdns`) are NOT touched. Backup at `/usr/data/guppyify-backup/`.
- **NO** — Minimal disable: `mv /usr/bin/Monitor /usr/bin/Monitor.disable` and same for `display-server` (the only ones that conflict with GuppyScreen because they hold `/dev/fb0`).

**v2 fixes vs v1** — Critical bugs found and fixed during testing:
- `pgrep -x guppyscreen` doesn't find the process when launched via `supervise-daemon`. Fixed by `guppy_pid()` helper using `ps | grep` on the full path with exclusion of `supervise-daemon`.
- `killall ... | while read line` decoupled signal delivery in busybox sh. Fixed by `kill_processes()` helper that runs killall directly and captures output separately.
- Initial kill list was 4 processes; extended to 9 after observing surviving Creality services in `ps`.
- Added a retry pass with `pkill -9 -f` for stubborn processes plus a final survivors report.
- Increased GuppyScreen startup wait window from 5s to 20s (supervise-daemon takes time to spawn the binary).

**Idempotent** — Yes via mode detection.

**Common failure modes** —
- "GuppyScreen failed to start" — check `tail /usr/data/printer_data/logs/guppyscreen.log` (LVGL init errors usually mean a screen size mismatch — verify the right tarball was downloaded).
- Touch unresponsive after install — `guppyconfig.json` calibration is screen-specific. Set `touch_calibrated: false` (handled by `install_personalization.sh` for E5M-CK).
- Creality processes survive the kill — they're respawned by `S99start_app`. The script removes that file in FULL disable mode; minimal mode relies on binary renaming.

---

### 4.12 `install_personalization.sh`

**Purpose** — Apply E5M-CK personalizations on top of a working install: Fluidd settings, GuppyScreen config, and boot logo.

**Generated because** — The base install gives a working but generic stack. Personalization makes it visually and functionally specific to E5M-CK: dark red theme everywhere, custom macros visible in Fluidd, custom fans/leds in GuppyScreen, custom boot logo.

**Architecture** — Single script with three independent sections, each gated by a `confirm()` prompt. The user can skip any section.

**Pre-conditions** — Working stack (Klipper, Moonraker, Fluidd, GuppyScreen). Network OK. `python3` available.

**Post-conditions** —
- Section 1 (Fluidd): all keys from `backup-fluidd-v1.36.4-fluidd.json` POSTed to `http://localhost:7125/server/database/item` under namespace `fluidd`. User must reload Fluidd in browser to see the new theme.
- Section 2 (GuppyScreen): `/usr/data/guppyscreen/guppyconfig.json` replaced with the repo version, modified to set `touch_calibrated: false` and `touch_calibration_coeff: null` (forces fresh touch calibration on first boot, regardless of which physical screen).
- Section 3 (Boot logo): all `/etc/logo/*.jpg` and `*.jpeg` replaced with `e5m_ck_logo.jpg`. Originals backed up at `/usr/data/logo_originals/`.

**Steps (per section)** —

*Section 1 — Fluidd settings:*
1. Download `backup-fluidd-v1.36.4-fluidd.json` from the repo.
2. Validate the JSON has `meta.app == "Fluidd"` and `meta.type == "settings-backup"`.
3. For each top-level key in `data` (charts, console, layout, macros, uiSettings, webcams), POST to `/server/database/item` with payload `{namespace: 'fluidd', key, value}`.
4. Report total/OK/FAIL counts.

*Section 2 — GuppyScreen config:*
1. Download `guppyconfig.json` from the repo.
2. Validate JSON parses and has `printers` key.
3. Patch in-memory: set `touch_calibrated = False`, `touch_calibration_coeff = None`.
4. Backup existing config at `guppyconfig.json.bak.<timestamp>`.
5. Stop GuppyScreen.
6. Deploy new config.
7. Restart GuppyScreen.

*Section 3 — Boot logo:*
1. Download `e5m_ck_logo.jpg` from the repo.
2. Validate it's a real JPEG (magic bytes `FF D8 FF`).
3. Backup all originals to `/usr/data/logo_originals/` (idempotent: skip if already backed up).
4. Overwrite all `/etc/logo/*.jpg` and `*.jpeg` with the new logo.
5. `sync` to flush.

**Idempotent** — Yes per section.

**Common failure modes** —
- POST to Moonraker DB fails with HTTP 4xx — likely Moonraker not reachable or namespace name wrong.
- Touch screen doesn't ask for calibration after deploy — verify `touch_calibrated: false` in the deployed file (the patch may have failed silently).
- Boot logo unchanged after reboot — `/etc/logo/` is on the read-only rootfs but mounted as overlayfs; the `cp` should work but a bad logo file (corrupt JPEG, wrong dimensions) might be silently rejected by the boot loader.

---

## 5. Recommended install order

For a **fresh install** on a stock Creality system, run in this order:

```
 1. install_factory_reset.sh        # optional, only if you want to wipe state first
 2. install_entware.sh
 3. install_klipper.sh
 4. install_gcode_shellcommand.sh
 5. install_klipper_patches.sh      # optional, suppresses the Creality MCU warning
 6. install_moonraker.sh
 7. install_nginx.sh
 8. install_fluidd.sh
 9. install_configs.sh              # deploys the printer.cfg etc.
10. install_eddy.sh                 # requires USB key, manual step
11. install_guppyscreen.sh          # requires interactive confirmation for Creality disable
12. install_personalization.sh      # optional, theme + macros + boot logo
13. sync && reboot                  # required after step 11/12 to validate full boot
```

After step 13, verify:
- Touchscreen shows GuppyScreen UI directly at boot (no Creality splash blocking it).
- SSH still works.
- Fluidd accessible at `http://<printer-ip>:4408/`.
- Klipper reports `state: ready`.

---

## 6. Update workflow

For an existing install that needs to be brought up to date:

| Component | How to update |
|---|---|
| Klipper | Update Manager in Fluidd, OR `cd /usr/data/klipper && git pull` and restart |
| Moonraker | Update Manager in Fluidd, OR re-run `install_moonraker.sh` (UPDATE mode) |
| Fluidd | Update Manager in Fluidd (handles itself) |
| GuppyScreen | Re-run `install_guppyscreen.sh` (will detect newer GitHub release) |
| Klipper patches | Re-run `install_klipper_patches.sh` (idempotent) |
| Configs | Re-run `install_configs.sh` (warning: overwrites local edits) |

Update Manager in Fluidd works for the first three because each install script sets up the `[update_manager]` section in `moonraker.conf` correctly during the initial install.

---

## 7. Debugging cheat sheet

When something breaks after an install or update, check these in order:

```sh
# 1. Are core services running?
ps | grep -E "klipper|moonraker|nginx|guppyscreen" | grep -v grep

# 2. Is Klipper ready?
curl -s http://localhost:7125/printer/info | python3 -m json.tool | head -10

# 3. Are there warnings in Klipper?
curl -s http://localhost:7125/printer/info | python3 -c "
import json, sys
print(json.load(sys.stdin)['result'].get('warnings', []))
"

# 4. Klipper log tail
tail -50 /usr/data/printer_data/logs/klippy.log

# 5. Moonraker log tail
tail -50 /usr/data/printer_data/logs/moonraker.log

# 6. GuppyScreen log tail
tail -50 /usr/data/printer_data/logs/guppyscreen.log

# 7. Who holds the framebuffer?
fuser /dev/fb0

# 8. Is anything listening on the expected ports?
netstat -tln | grep -E ':4408|:4409|:7125'

# 9. Disk space
df -h /usr/data /opt

# 10. Recent kernel messages
dmesg | tail -30
```

If a script fails midway, the backups are at:
- `/usr/data/E5M_CK/` — most install scripts
- `/usr/data/guppyify-backup/` — GuppyScreen install
- `/usr/data/logo_originals/` — boot logo
- `/usr/data/klipper/klippy/configfile.py.bak.before_e5m_ck` — Klipper patches
- `/etc/init.d/S56moonraker_service.before_E5M_CK` — Moonraker init script
- `/etc/init.d/S50nginx.bak` — nginx init script

In the worst case, `install_factory_reset.sh` + USB-key trigger will restore stock Creality state without losing anything in `/usr/data/` (which Creality's reset preserves by design).

---

## References

- Project repo: https://github.com/christianKEL/E5M-CK
- Project documentation: https://e5mdocumentation.kinsta.cloud/
- Related memos:
  - `MEMO_c_helper_FR.md` — origin and traceability of `c_helper.so`
  - `MEMO_moonraker_venv_FR.md` — origin and traceability of `moonraker-env.tar.gz`
  - `MEMO_klipper_dirty_FR.md` — explanation of the various `-dirty` markers and the `STEPPER_STEP_BOTH_EDGE` warning
- GitHub issues:
  - #1 STEPPER_STEP_BOTH_EDGE missing on Creality MCUs
  - #2 Klipper HOST `-dirty` due to GuppyScreen extras (by design)

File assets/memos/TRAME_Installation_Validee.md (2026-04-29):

# TRAME D'INSTALLATION VALIDÉE
## BTT Eddy USB + Klipper Mainline + GuppyScreen
## Creality Ender 5 Max — Nebula Pad
### Christian KELHETTER — Avril 2026

---

> **Ce document est mis à jour en temps réel.**
> Chaque étape est consignée UNIQUEMENT après validation sur machine réelle.
> Ce document servira de base pour l'automatisation future.

---

## PRÉREQUIS MATÉRIELS

- Creality Ender 5 Max
- Nebula Pad d'origine
- BTT Eddy USB
- BTT Pad 7 (pour compiler le firmware Eddy — une seule fois)
- Clé USB FAT32
- PC Windows avec SSH configuré

---

## ÉTAPE 1 — FACTORY RESET ✅

**Objectif :** Remettre le Nebula dans son état d'usine.

**Procédure :**
1. Créer un fichier vide nommé `factory_reset` (sans extension) sur une clé USB FAT32
2. Éteindre le Nebula
3. Brancher la clé USB sur le Nebula
4. Allumer le Nebula
5. Attendre le redémarrage automatique

**Résultat :**
- Klipper fork Creality actif : `/usr/share/klipper/klippy/klippy.py`
- Config active : `/usr/data/printer_data/config/printer.cfg`
- Moonraker : absent
- Helper Script : absent

---

## ÉTAPE 2 — INSTALLATION HELPER SCRIPT ✅

**Objectif :** Installer Moonraker, Fluidd et les outils de base.

**Commande SSH :**
```bash
git clone --depth 1 https://github.com/Guilouz/Creality-Helper-Script.git /usr/data/helper-script
```

**Puis lancer le script :**
```bash
sh /usr/data/helper-script/helper.sh
```

**Dans le menu Helper Script, installer :**
- Moonraker + Nginx
- Fluidd (port 4408)
- Klipper Gcode Shell Command

**Résultat validé :**
- Moonraker actif sur port 7125 ✅
- Fluidd accessible sur http://[IP]:4408 ✅
- Klipper fork Creality `ready` version `09faed31-dirty` ✅

---

## ÉTAPE 3 — COMPILATION c_helper.so MIPS ✅

**Objectif :** Compiler `c_helper.so` pour MIPS XBurst2 avec le toolchain Ingenic officiel.

**Prérequis :** PC x86_64 Linux (ou GitHub Codespaces — gratuit, dans le navigateur)

**Toolchain requis :** Ingenic GCC 5.2 + nan2008 (Dafang-Hacks, disponible sur GitHub)

```bash
# Sur GitHub Codespaces (https://github.com/codespaces) — repo Klipper3d/klipper

# 1. Cloner le toolchain Ingenic GCC 5.2 x86_64
git clone --depth 1 https://github.com/Dafang-Hacks/mips-gcc520-glibc222-64bit-r3.2.1 \
  ~/ingenic-toolchain

# 2. Cloner Klipper mainline (ou utiliser le repo ouvert dans Codespaces)
# Le repo klipper est déjà disponible dans /workspaces/klipper

# 3. Compiler c_helper.so avec flags nan2008
cd /workspaces/klipper/klippy/chelper

~/ingenic-toolchain/bin/mips-linux-gnu-gcc -shared -fPIC -O2 \
    -mnan=2008 -mfp64 -mabs=2008 \
    $(ls *.c) \
    -o c_helper.so

# 4. Vérifier les flags (doit afficher 0x70001407 avec nan2008)
~/ingenic-toolchain/bin/mips-linux-gnu-readelf -h c_helper.so | grep "Flags"
# Résultat attendu : Flags: 0x70001407, noreorder, pic, cpic, nan2008, o32, mips32r2

# 5. Vérifier les dépendances (doit afficher uniquement libc.so.6)
~/ingenic-toolchain/bin/mips-linux-gnu-readelf -d c_helper.so | grep "NEEDED"
```

**Transfert vers le Nebula :**
```bash
# Télécharger c_helper.so depuis Codespaces → PC Windows
# (clic droit sur le fichier dans l'explorateur Codespaces → Download)

# Depuis PowerShell Windows → Pad 7
scp C:\Users\...\Downloads\c_helper.so biqu@[IP_PAD7]:/tmp/c_helper.so

# Depuis Pad 7 → Nebula
scp /tmp/c_helper.so root@[IP_NEBULA]:/usr/data/klipper/klippy/chelper/c_helper.so

# Sauvegarder dans E5M_CK
cp /usr/data/klipper/klippy/chelper/c_helper.so /usr/data/E5M_CK/c_helper.so
```

**Validation :**
```bash
/usr/share/klippy-env/bin/python3 -c \
  "import ctypes; ctypes.CDLL('/usr/data/klipper/klippy/chelper/c_helper.so'); print('OK')"
# Résultat attendu : OK
```

**Résultat validé :**
- Flags : `0x70001407` avec `nan2008` ✅
- Dépendance : `libc.so.6` uniquement ✅
- Chargement Python : `OK` ✅

---

## ÉTAPE 4 — INSTALLATION KLIPPER MAINLINE ✅

**Objectif :** Installer Klipper mainline `v0.13.0-628-g373f200ca` sur le Nebula.

```bash
# 1. Créer dossier de travail E5M_CK
mkdir -p /usr/data/E5M_CK

# 2. Backup du service Klipper Creality
cp /etc/init.d/S55klipper_service /usr/data/E5M_CK/S55klipper_service.creality.bak

# 3. Cloner Klipper mainline
git clone https://github.com/Klipper3d/klipper.git /usr/data/klipper

# 4. Placer c_helper.so compilé (voir Étape 3)
cp /usr/data/E5M_CK/c_helper.so /usr/data/klipper/klippy/chelper/

# 5. Copier modules Creality nécessaires
cp /usr/share/klipper/klippy/extras/gcode_shell_command.py /usr/data/klipper/klippy/extras/
cp /usr/share/klipper/klippy/extras/custom_macro.py /usr/data/klipper/klippy/extras/

# 6. Créer config_mainline
mkdir -p /usr/data/printer_data/config_mainline
cp /usr/data/printer_data/config/*.cfg /usr/data/printer_data/config_mainline/
cp /usr/data/printer_data/config/moonraker.conf /usr/data/printer_data/config_mainline/
```

**Patches printer.cfg :**
```bash
python3 << 'EOF'
sections_to_comment = [
    'mcu leveling_mcu', 'mcu rpi', 'bl24c16f', 'prtouch_v2',
    'hx711s', 'accel_chip_proxy', 'resonance_tester',
    'filter', 'dirzctl', 'temperature_sensor mcu_temp',
]
with open('/usr/data/printer_data/config_mainline/printer.cfg', 'r') as f:
    lines = f.readlines()
result = []
in_section = False
for line in lines:
    stripped = line.strip()
    if stripped.startswith('[') and stripped.endswith(']'):
        section = stripped[1:-1].strip()
        in_section = any(section == s for s in sections_to_comment)
    elif stripped.startswith('['):
        in_section = False
    if in_section and stripped and not stripped.startswith('#'):
        result.append('#' + line)
    else:
        result.append(line)
content = ''.join(result)
content = content.replace('CXSAVE_CONFIG', 'SAVE_CONFIG')
content = content.replace('max_accel_to_decel: 5000', 'minimum_cruise_ratio: 0.5')
content = content.replace('[include sensorless.cfg]', '#[include sensorless.cfg]')
with open('/usr/data/printer_data/config_mainline/printer.cfg', 'w') as f:
    f.write(content)
print("Done")
EOF
```

**Modifier stepper_z et bed_mesh :**
```bash
python3 << 'EOF'
import re
with open('/usr/data/printer_data/config_mainline/printer.cfg', 'r') as f:
    content = f.read()
content = re.sub(
    r'(endstop_pin: tmc2209_stepper_z:virtual_endstop.*)',
    r'#\1\nendstop_pin: probe:z_virtual_endstop\nhoming_retract_dist: 0',
    content
)
content = re.sub(r'^(position_endstop: 0.*)$', r'#\1', content, flags=re.MULTILINE)
old_mesh = re.search(r'\[bed_mesh\].*?(?=\n\[)', content, re.DOTALL)
if old_mesh:
    new_mesh = """[bed_mesh]
horizontal_move_z: 2
scan_overshoot: 8
speed: 200
mesh_min: 29, 5
mesh_max: 371, 395
probe_count: 40, 40
fade_start: 1.0
fade_end: 20
fade_target: 0
mesh_pps: 4, 4
algorithm: bicubic
bicubic_tension: 0.2
"""
    content = content[:old_mesh.start()] + new_mesh + content[old_mesh.end():]
with open('/usr/data/printer_data/config_mainline/printer.cfg', 'w') as f:
    f.write(content)
print("Done")
EOF
```

**Créer eddy.cfg :**
```bash
EDDY_SERIAL=$(ls /dev/serial/by-id/ | grep rp2040)
cat > /usr/data/printer_data/config_mainline/eddy.cfg << EOF
[mcu eddy]
serial: /dev/serial/by-id/${EDDY_SERIAL}

[temperature_sensor btt_eddy_mcu]
sensor_type: temperature_mcu
sensor_mcu: eddy
min_temp: 10
max_temp: 100

[probe_eddy_current btt_eddy]
sensor_type: ldc1612
z_offset: 1.0
i2c_mcu: eddy
i2c_bus: i2c0f
x_offset: 24
y_offset: 0

[temperature_probe btt_eddy]
sensor_type: Generic 3950
sensor_pin: eddy:gpio26
horizontal_move_z: 2
EOF
```

**Créer homing.cfg :**
```bash
cat > /usr/data/printer_data/config_mainline/homing.cfg << 'EOF'
[homing_override]
axes: xyz
set_position_z: 0
gcode:
  G90
  {% set home_all = 'X' not in params and 'Y' not in params and 'Z' not in params %}
  G1 Z30 F600
  {% if home_all or 'X' in params or 'Y' in params %}
    G28 Y
    G1 Y400 F2400
  {% endif %}
  {% if home_all or 'X' in params %}
    G28 X
    G1 X380 F2400
  {% endif %}
  {% if home_all or 'Z' in params %}
    G0 X200 Y200 F6000
    G28 Z
    G1 Z10 F600
  {% endif %}
EOF
```

**Ajouter includes et modifier service :**
```bash
sed -i '1s/^/[include eddy.cfg]\n[include homing.cfg]\n/' \
  /usr/data/printer_data/config_mainline/printer.cfg

sed -i 's|PY_SCRIPT=/usr/share/klipper/klippy/klippy.py|PY_SCRIPT=/usr/data/klipper/klippy/klippy.py|' \
  /etc/init.d/S55klipper_service
sed -i 's|$PRINTER_CONFIG_DIR/printer.cfg|/usr/data/printer_data/config_mainline/printer.cfg|' \
  /etc/init.d/S55klipper_service
```

**Résultat validé :**
- Klipper mainline `v0.13.0-628-g373f200ca` : `ready` ✅
- Commit : `373f200ca` ✅
- Eddy USB détecté : `usb-Klipper_rp2040_50445059303E9B1C-if00` ✅

---

## ROLLBACK CREALITY

```bash
sed -i 's|/usr/data/klipper/klippy/klippy.py|/usr/share/klipper/klippy/klippy.py|' /etc/init.d/S55klipper_service
sed -i 's|config_mainline/printer.cfg|config/printer.cfg|' /etc/init.d/S55klipper_service
/etc/init.d/S55klipper_service restart
```

---

## ÉTAPE 5 — FLASH BTT EDDY USB ✅

**Objectif :** Flasher le firmware Klipper mainline sur l'Eddy.

**Compiler btteddy.uf2** (sur GitHub Codespaces, commit identique à Klipper mainline) :
```bash
# Dans Codespaces — repo klipper déjà cloné
cd /workspaces/klipper
make clean
make menuconfig
# Paramètres :
#   Micro-controller Architecture → Raspberry Pi RP2040
#   Bootloader offset             → No bootloader
#   Flash chip                    → GENERIC_03H with CLKDIV 4
#   Communication interface       → USB
make
# Résultat : out/klipper.uf2 (version v0.13.0-628-g373f200ca)
```

**Flash via méthode UF2 sur le Nebula :**
```bash
# 1. Brancher l'Eddy en mode BOOT (bouton maintenu) sur le port USB Nebula
# 2. Vérifier détection bootloader
lsusb | grep "2e8a:0003"

# 3. L'Eddy est monté automatiquement
mount | grep sda
# → /dev/sda1 on /tmp/udisk/sda1 type vfat

# 4. Copier le firmware (flash automatique)
cp /usr/data/E5M_CK/btteddy.uf2 /tmp/udisk/sda1/
sync
# L'Eddy redémarre automatiquement

# 5. Vérifier que l'Eddy est en mode Klipper
ls /dev/serial/by-id/
# → usb-Klipper_rp2040_50445059303E9B1C-if00
```

**Résultat validé :**
- Flash UF2 sans outil supplémentaire ✅
- Serial : `usb-Klipper_rp2040_50445059303E9B1C-if00` ✅

---

## ÉTAPE 6 — GUPPYSCREEN ✅

**Installation :** via Helper Script → Customize → GuppyScreen

**Copier les modules dans klipper mainline :**
```bash
cp /usr/data/guppyscreen/k1_mods/guppy_module_loader.py /usr/data/klipper/klippy/extras/
cp /usr/data/guppyscreen/k1_mods/calibrate_shaper_config.py /usr/data/klipper/klippy/extras/
cp /usr/data/guppyscreen/k1_mods/tmcstatus.py /usr/data/klipper/klippy/extras/

mkdir -p /usr/data/printer_data/config_mainline/GuppyScreen
cp /usr/data/guppyscreen/scripts/guppy_cmd.cfg \
   /usr/data/printer_data/config_mainline/GuppyScreen/

sed -i '1s/^/[include GuppyScreen\/*.cfg]\n/' \
   /usr/data/printer_data/config_mainline/printer.cfg
```

**Thème rouge :**
```bash
python3 -c "
import json
with open('/usr/data/guppyscreen/guppyconfig.json', 'r') as f:
    c = json.load(f)
c['theme'] = 'red'
with open('/usr/data/guppyscreen/guppyconfig.json', 'w') as f:
    json.dump(c, f, indent=4)
"
```

**Macros visibles (uniquement celles pour calibration Eddy) :**
```bash
python3 << 'EOF'
import urllib.request, json

macros_hidden = [
    "ACCURATE_G28", "AUTOTUNE_SHAPERS", "BEDPID", "CANCEL_PRINT",
    "FINISH_INIT", "FIRST_FLOOR_PAUSE", "FIRST_FLOOR_PAUSE_POSITION",
    "FIRST_FLOOR_RESUME", "G29", "GREEN_LED_OFF", "GREEN_LED_ON",
    "INPUTSHAPER", "LIGHT_LED_OFF", "LIGHT_LED_ON", "LOAD_MATERIAL",
    "M106", "M107", "M204", "M205", "M600", "M900", "PAUSE",
    "PRINTER_PARAM", "PRINT_CALIBRATION_EXT", "PRINT_FINI_ZDN",
    "QUIT_MATERIAL", "RED_LED_OFF", "RED_LED_ON", "RESUME",
    "STRUCTURE_PARAM", "TUNOFFINPUTSHAPER", "YELLOW_LED_OFF",
    "YELLOW_LED_ON", "ZZ_OFFSET_TEST", "Z_OFFSET_TEST",
    "GUPPY_SHAPERS", "GUPPY_EXCITATE_AXIS_AT_FREQ",
    "GUPPY_BELTS_SHAPER_CALIBRATION"
]
settings = {
    "SET_KINEMATIC_Z_200": {"hidden": False},
    "CENTER_TOOLHEAD": {"hidden": False}
}
for m in macros_hidden:
    settings[m] = {"hidden": True}

data = json.dumps({
    "namespace": "guppyscreen",
    "key": "macros.settings",
    "value": settings
}).encode()
req = urllib.request.Request(
    "http://localhost:7125/server/database/item",
    data=data,
    headers={"Content-Type": "application/json"},
    method="POST"
)
print("OK:", urllib.request.urlopen(req).status)
EOF
```

**Macros créées dans `GuppyScreen/macros_guppy.cfg` :**
```ini
[gcode_macro SET_KINEMATIC_Z_200]
description: SET_KINEMATIC Z 200
gcode:
  SET_KINEMATIC_POSITION Z=200

[gcode_macro CENTER_TOOLHEAD]
description: Centre la tête d'impression X=200 Y=200
gcode:
  G90
  G0 X200 Y200 F6000
```

---

## ÉTAPE 7 — CALIBRATION EDDY ✅

**Ordre des opérations :**
1. Homing XY depuis GuppyScreen
2. `CENTER_TOOLHEAD` depuis GuppyScreen
3. `SET_KINEMATIC_Z_200` depuis GuppyScreen
4. Descendre le plateau manuellement à ~20mm sous la buse (flèches Z GuppyScreen)

**A — Drive Current :**
```
LDC_CALIBRATE_DRIVE_CURRENT CHIP=btt_eddy
SAVE_CONFIG
# Résultat : reg_drive_current: 15
```

**B — Mapping hauteurs :**
```
G28 X Y → CENTER_TOOLHEAD → SET_KINEMATIC_Z_200
Descendre plateau au contact papier
SET_KINEMATIC_POSITION Z=0
G1 Z1 F300
PROBE_EDDY_CURRENT_CALIBRATE CHIP=btt_eddy
SAVE_CONFIG
```

**C — Vérification Z=0 :**
```
G28 → vérifier papier → babystepping si besoin → Save
```

**D — Bed Mesh :**
```
BED_MESH_CALIBRATE METHOD=rapid_scan
SAVE_CONFIG
```

**Résultat validé :**
- `reg_drive_current: 15` ✅
- Z=0 correct au papier ✅
- Bed mesh 40x40 points ✅

---

## ÉTAPE 8 — CORRECTIONS ET PATCHES ✅

**Supprimer avertissement `z_offset` deprecated dans `eddy.cfg` :**
```bash
# Remplacer z_offset par descend_z (nouveau paramètre Klipper mainline)
# Supprimer la ligne z_offset et ajouter descend_z: 3.0
```

**Corriger `max_accel` trop élevé (100000 → 10000) :**
```bash
sed -i 's/max_accel: 100000/max_accel: 10000/' \
  /usr/data/printer_data/config_mainline/printer.cfg
```

**Corriger `mesh_max` Y pour éviter sondage hors plateau :**
```bash
sed -i 's/mesh_max: 371, 395/mesh_max: 371, 385/' \
  /usr/data/printer_data/config_mainline/printer.cfg
```

**Supprimer avertissement MCU deprecated (STEPPER_STEP_BOTH_EDGE) :**
```bash
sed -i '105s/^/# /' /usr/data/klipper/klippy/stepper.py
rm /usr/data/klipper/klippy/stepper.pyc
```

**Supprimer avertissement Moonraker config folder :**
```bash
# Renommer config Creality et créer symlink
mv /usr/data/printer_data/config /usr/data/printer_data/config_creality_bak
ln -sf /usr/data/printer_data/config_mainline /usr/data/printer_data/config

# Supprimer config_path deprecated dans moonraker.conf si présent
sed -i '/config_path: \/usr\/data\/printer_data\/config_mainline/d' \
  /usr/data/printer_data/config_mainline/moonraker.conf
```

**Rollback Creality mis à jour :**
```bash
sed -i 's|/usr/data/klipper/klippy/klippy.py|/usr/share/klipper/klippy/klippy.py|' /etc/init.d/S55klipper_service
sed -i 's|config_mainline/printer.cfg|config/printer.cfg|' /etc/init.d/S55klipper_service
rm /usr/data/printer_data/config
mv /usr/data/printer_data/config_creality_bak /usr/data/printer_data/config
/etc/init.d/S55klipper_service restart
```

**Switch mainline :**
```bash
sed -i 's|/usr/share/klipper/klippy/klippy.py|/usr/data/klipper/klippy/klippy.py|' /etc/init.d/S55klipper_service
sed -i 's|config/printer.cfg|config_mainline/printer.cfg|' /etc/init.d/S55klipper_service
mv /usr/data/printer_data/config /usr/data/printer_data/config_creality_bak
ln -sf /usr/data/printer_data/config_mainline /usr/data/printer_data/config
/etc/init.d/S55klipper_service restart
```

---

## ÉTAPE 9 — START G-CODE ORCA (à faire)

---

## NOTES TECHNIQUES VALIDÉES

| Observation | Détail |
|---|---|
| Direction Z | Z+ descend le plateau (inverse convention habituelle) |
| Ordre homing CoreXY | Y en premier, puis X — obligatoire |
| Endstops X/Y | Physiques au MAXIMUM (X≈400, Y≈401) |
| `homing_positive_dir` | `true` obligatoire sur X et Y |
| Klipper mainline sur Nebula | Commit `373f200ca` (v0.13.0-628), Python 3.8.2, MIPS 32-bit |
| `c_helper.so` compilation | Toolchain Ingenic GCC 5.2 (Dafang-Hacks GitHub) sur x86_64 |
| `c_helper.so` flags requis | `-mnan=2008 -mfp64 -mabs=2008` → flags `0x70001407` |
| `c_helper.so` plateforme compilation | GitHub Codespaces (x86_64) — Pad 7 est ARM64, incompatible |
| `temperature_mcu` GD32F303 | Non supporté en mainline → commenter |
| z_offset Eddy | Deprecated → remplacer par `descend_z: 3.0` |
| MCU deprecated warning | Commenté dans `stepper.py` ligne 105 |
| Moonraker config folder | Symlink `/config` → `config_mainline` |
| GuppyScreen macros cachées | Via API Moonraker namespace `guppyscreen` |
| GuppyScreen thème | `guppyconfig.json` → `"theme": "red"` |
| `max_accel` Creality | 100000 par défaut → corriger à 10000 |
| `mesh_min/max` calcul | Coordonnées SONDE (Eddy), pas buse. Klipper ne convertit PAS automatiquement |
| `reg_drive_current` Eddy | 15 (valeur nominale validée) |
| Offsets Eddy validés | `x_offset: 38`, `y_offset: 6` (mesurés physiquement + rayon capteur) |

---

## FORMULE CALCUL AUTOMATIQUE mesh_min / mesh_max

**À recalculer si les offsets Eddy changent.**

Variables :
- `X_OFFSET` = x_offset dans eddy.cfg
- `Y_OFFSET` = y_offset dans eddy.cfg  
- `SCAN_OVERSHOOT` = scan_overshoot dans printer.cfg (défaut: 8)
- `POS_MAX_X` = position_max du stepper_x
- `POS_MAX_Y` = position_max du stepper_y

Formule :
```
mesh_min_x = X_OFFSET + SCAN_OVERSHOOT
mesh_min_y = Y_OFFSET
mesh_max_x = POS_MAX_X - X_OFFSET - SCAN_OVERSHOOT
mesh_max_y = POS_MAX_Y - Y_OFFSET
```

**Script de calcul automatique :**
```bash
python3 << 'EOF'
X_OFFSET = 38
Y_OFFSET = 6
SCAN_OVERSHOOT = 8
POS_MAX_X = 406
POS_MAX_Y = 401

mesh_min_x = X_OFFSET + SCAN_OVERSHOOT
mesh_min_y = Y_OFFSET
mesh_max_x = POS_MAX_X - X_OFFSET - SCAN_OVERSHOOT
mesh_max_y = POS_MAX_Y - Y_OFFSET

print(f"mesh_min: {mesh_min_x}, {mesh_min_y}")
print(f"mesh_max: {mesh_max_x}, {mesh_max_y}")

import re
with open('/usr/data/printer_data/config_mainline/printer.cfg', 'r') as f:
    content = f.read()
content = re.sub(r'mesh_min:.*', f'mesh_min: {mesh_min_x}, {mesh_min_y}', content)
content = re.sub(r'mesh_max:.*', f'mesh_max: {mesh_max_x}, {mesh_max_y}', content)
with open('/usr/data/printer_data/config_mainline/printer.cfg', 'w') as f:
    f.write(content)
print("printer.cfg mis à jour.")
EOF
```

**Valeurs validées sur l'Ender 5 Max :**
```
mesh_min: 46, 6
mesh_max: 360, 395
```

---

*Document mis à jour au fil des étapes validées.*

---

## ÉTAPE 9 — MACROS DE CALIBRATION ✅

**Fichier :** `/usr/data/printer_data/config_mainline/macros_calibration.cfg`

**Include dans printer.cfg :**
```bash
sed -i '1s/^/[include macros_calibration.cfg]\n/' \
  /usr/data/printer_data/config_mainline/printer.cfg
```

**Règles de rédaction :**
- Code et commentaires en anglais
- Messages RESPOND en anglais
- Emojis : ✅ confirmation, 🔄 attente, ℹ️ information
- Paramètres optionnels avec valeurs par défaut

**CAL_BED_Z_TILT** — Nivellement mécanique du bed (G28 + FORCE_MOVE x8 + G28 final)

**CAL_BED_PID** — Calibration PID du bed (paramètre TEMP, défaut 65°C)
```
CAL_BED_PID           # → 65°C
CAL_BED_PID TEMP=80   # → 80°C
```

**Correction heater_bed :**
```
pwm_cycle_time: 0.3   # ajouté dans [heater_bed]
```

**Rendre visibles dans GuppyScreen :**
```python
current["CAL_BED_Z_TILT"] = {"hidden": False}
current["CAL_BED_PID"] = {"hidden": False}
```

---

## ÉTAPE 10 — START G-CODE ORCA (à faire)

---

## ÉTAPE 3b — PATCH CREALITY SERVERS ✅

**Objectif :** Neutraliser `app-server` et `master-server` pour éviter les interférences avec Klipper mainline.

**Problème :** Ces deux processus Creality tournent en parallèle de Klipper mainline et peuvent :
- `app-server` : se connecter au socket Klipper et envoyer des commandes non sollicitées
- `master-server` : envoyer `SET_HEATER_TEMPERATURE HEATER=heater_bed` de façon autonome

**Solution :** Patch binaire (même longueur pour éviter de corrompre les offsets) :
- `app-server` : `/tmp/klippy_uds` → `/tmp/klippy_udx` (connexion au socket impossible)
- `master-server` : `SET_HEATER_TEMPERATURE` → `NOP_HEATER_TEMPERATURE` (commandes bed ignorées)

**Script :** `/usr/data/E5M_CK/patch_servers.sh`
```bash
sh /usr/data/E5M_CK/patch_servers.sh
reboot
```

**Notes :**
- Backup automatique des binaires originaux (`.orig`) avant patch
- `wifi-server`, `audio-server`, `upgrade-server` non affectés
- Rollback : `cp /usr/bin/app-server.orig /usr/bin/app-server && cp /usr/bin/master-server.orig /usr/bin/master-server`

---

## CONTENU COMPLET — macros_calibration.cfg

```ini
# ═══════════════════════════════════════════════════════
# CALIBRATION MACROS — Ender 5 Max
# ═══════════════════════════════════════════════════════

# ─── MECHANICAL BED LEVELING ───
# Synchronizes the 4 Z motors by forcing movement
# Ends with a full G28 ready to print
[gcode_macro CAL_BED_Z_TILT]
description: Mechanical bed Z tilt leveling via FORCE_MOVE
gcode:
  RESPOND TYPE=command MSG="🔄 Starting mechanical bed leveling..."
  RESPOND TYPE=command MSG="🔄 Homing all axes..."
  G28
  RESPOND TYPE=command MSG="✅ Homing complete"
  RESPOND TYPE=command MSG="🔄 Moving bed to lowest position..."
  G1 Z400 F300
  RESPOND TYPE=command MSG="🔄 Synchronizing Z motors - step 1/8..."
  FORCE_MOVE STEPPER=stepper_z DISTANCE=5 VELOCITY=5
  RESPOND TYPE=command MSG="🔄 Synchronizing Z motors - step 2/8..."
  FORCE_MOVE STEPPER=stepper_z DISTANCE=5 VELOCITY=5
  RESPOND TYPE=command MSG="🔄 Synchronizing Z motors - step 3/8..."
  FORCE_MOVE STEPPER=stepper_z DISTANCE=5 VELOCITY=5
  RESPOND TYPE=command MSG="🔄 Synchronizing Z motors - step 4/8..."
  FORCE_MOVE STEPPER=stepper_z DISTANCE=5 VELOCITY=5
  RESPOND TYPE=command MSG="🔄 Synchronizing Z motors - step 5/8..."
  FORCE_MOVE STEPPER=stepper_z DISTANCE=5 VELOCITY=5
  RESPOND TYPE=command MSG="🔄 Synchronizing Z motors - step 6/8..."
  FORCE_MOVE STEPPER=stepper_z DISTANCE=5 VELOCITY=5
  RESPOND TYPE=command MSG="🔄 Synchronizing Z motors - step 7/8..."
  FORCE_MOVE STEPPER=stepper_z DISTANCE=5 VELOCITY=5
  RESPOND TYPE=command MSG="🔄 Synchronizing Z motors - step 8/8..."
  FORCE_MOVE STEPPER=stepper_z DISTANCE=5 VELOCITY=5
  RESPOND TYPE=command MSG="🔄 Raising bed..."
  FORCE_MOVE STEPPER=stepper_z DISTANCE=-200 VELOCITY=5
  RESPOND TYPE=command MSG="🔄 Final homing..."
  G28
  RESPOND TYPE=command MSG="✅ Mechanical leveling complete - Printer is ready"

# ─── BED PID CALIBRATION ───
# Calibrates PID parameters for the heated bed
# Optional parameter: TEMP (default: 65°C)
# Usage: CAL_BED_PID or CAL_BED_PID TEMP=80
[gcode_macro CAL_BED_PID]
description: Bed PID calibration (default 65C, usage: CAL_BED_PID TEMP=80)
gcode:
  {% set temp = params.TEMP|default(65)|int %}
  RESPOND TYPE=command MSG="🔄 Starting bed PID calibration at {temp}°C..."
  RESPOND TYPE=command MSG="ℹ️ This may take several minutes"
  PID_CALIBRATE HEATER=heater_bed TARGET={temp}
  RESPOND TYPE=command MSG="✅ Bed PID calibration complete - Run SAVE_CONFIG to save"
```

> Note : `POPUP_TEST` macro présente dans le fichier — à supprimer en production.

---

## CONFIGURATION FLUIDD — Axe Z inversé ✅

Sur l'Ender 5 Max, Z+ descend le plateau. Fluidd doit être configuré en conséquence.

**Commande à exécuter après installation de Fluidd :**
```bash
python3 << 'EOF'
import urllib.request, json

data = json.dumps({
    "namespace": "fluidd",
    "key": "uiSettings.general.axis",
    "value": {"z": {"inverted": True}}
}).encode()

req = urllib.request.Request(
    "http://localhost:7125/server/database/item",
    data=data,
    headers={"Content-Type": "application/json"},
    method="POST"
)
print("OK:", urllib.request.urlopen(req).status)
EOF
```

---

## MACROS CALIBRATION — Eddy et Bed Mesh

**Ajoutées dans `macros_calibration.cfg` :**

**`CAL_EDDY_DRIVE_CURRENT`** — Recalibration drive current Eddy
```
G28 X Y → CENTER_TOOLHEAD → SET_KINEMATIC_Z_200
Descendre manuellement à ~20mm → LDC_CALIBRATE_DRIVE_CURRENT CHIP=btt_eddy → SAVE_CONFIG
```

**`CAL_EDDY_MAPPING`** — Recalibration mapping hauteurs Eddy
```
G28 X Y → CENTER_TOOLHEAD → SET_KINEMATIC_Z_200
Descendre au contact papier → SET_KINEMATIC_POSITION Z=0 → G1 Z1 F300
PROBE_EDDY_CURRENT_CALIBRATE CHIP=btt_eddy → SAVE_CONFIG
```

**`CAL_BED_MESH`** — Bed mesh complet 40x40 points
```
G28 → BED_MESH_CLEAR → BED_MESH_CALIBRATE METHOD=rapid_scan → SAVE_CONFIG
```

**PID validés :**
```
Bed  : pid_Kp=53.200  pid_Ki=0.414  pid_Kd=1707.722
Nozzle: pid_Kp=32.043 pid_Ki=2.967  pid_Kd=86.514
```

---

## PATCH CRITIQUE — heater_bed et extruder control

**Problème :** Dans la config Creality, `control` est commenté dans `[heater_bed]` et `[extruder]`.
Klipper mainline exige que ce paramètre soit présent et non commenté.
Après un `SAVE_CONFIG` suite à une calibration PID, Klipper peut se retrouver en erreur.

**Fix :**
```bash
sed -i 's/#control = pid/control = pid/' \
  /usr/data/printer_data/config_mainline/printer.cfg
sed -i 's/#control = watermark/control = watermark/' \
  /usr/data/printer_data/config_mainline/printer.cfg
```

**À intégrer dans le script d'installation** lors du patch de `printer.cfg`,
avant tout démarrage de Klipper mainline.

---

## RÈGLE CRITIQUE — Ne jamais écrire après #*# SAVE_CONFIG

**La section `#*# <--- SAVE_CONFIG --->` doit TOUJOURS être en toute fin de `printer.cfg`.**

Klipper écrit et lit exclusivement depuis la fin du fichier. Toute ligne ajoutée après `#*#` corrompt la lecture des paramètres sauvegardés (PID, z_offset, bed_mesh, etc.).

**Règles :**
- ❌ Ne jamais utiliser `cat >>` ou `echo >>` sur `printer.cfg`
- ✅ Toujours insérer avant le bloc `#*#` via `sed` ou `python3`
- ✅ Vérifier après chaque modification : `tail -5 printer.cfg` → `#*#` doit être en dernier

**Méthode d'insertion correcte :**
```bash
python3 << 'EOF'
with open('/usr/data/printer_data/config_mainline/printer.cfg', 'r') as f:
    content = f.read()

new_section = """
[ma_nouvelle_section]
parametre: valeur

"""

# Insérer AVANT le bloc SAVE_CONFIG
content = content.replace(
    '#*# <---------------------- SAVE_CONFIG ---------------------->',
    new_section + '#*# <---------------------- SAVE_CONFIG ---------------------->'
)

with open('/usr/data/printer_data/config_mainline/printer.cfg', 'w') as f:
    f.write(content)
print("Done")
EOF
```

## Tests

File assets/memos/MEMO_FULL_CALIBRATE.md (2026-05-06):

# MEMO — FULL_CALIBRATE workflow

**Project**: E5M-CK
**Date**: 2026-05-06
**Scope**: BTT Eddy USB on Ender 5 Max, Klipper mainline

---

## 1. Problem statement

The BTT Eddy probe is highly sensitive to the temperature of its sensing
coil. The frequency/Z calibration table and the `tap_threshold` value
calibrated at one coil temperature are only valid within a narrow
window (typically ±5 °C) around that temperature. Outside of that
window, taps fail with `insufficient slope delta`, `invalid depress
distance`, or `Probe triggered prior to movement`, and scan readings
report a Z position several mm away from the true bed surface.

A persistent calibration is therefore unreliable across thermal
sessions: a print may start with the coil cold (≈ 30 °C), warm up to
its operating point during heat soak, and end with the coil at yet
another temperature once chamber convection stabilises. There is no
"good enough for all conditions" set of values.

## 2. Strategy: recalibrate at every print

Instead of trying to find robust persisted values, the chosen approach
is to **rebuild the entire Eddy state at the beginning of each print**,
in the actual thermal conditions of that print:

1. Heat the bed to print temperature
2. Heat the nozzle to 140 °C (warm enough for tap mechanics to work,
   cold enough to avoid filament ooze that would foul the bed)
3. Heat-soak 5 min so the coil reaches a stable temperature
4. Run `FULL_CALIBRATE`, which rebuilds:
   - `tap_threshold` (re-calibrated from current slope coefficients)
   - kinematic Z=0 (located by tap, median of 5 samples)
   - the frequency/Z table (rebuilt around the freshly located Z=0)
5. Run `BED_MESH_CALIBRATE METHOD=rapid_scan` with the fresh table
6. Heat the nozzle to print temperature, brush off the ooze drop,
   then `FINAL_TAP_OFFSET` to compensate for hotend thermal expansion
   (140 °C → print temp delta is typically 60–100 °C, producing
   ~50–100 µm of nozzle extension)
7. Prime line, print

Total overhead: ~4–5 min added to the start G-code, dominated by the
heat soak (5 min) and the Eddy table rebuild (~3 min). The user
intervention is zero.

## 3. Why a custom Klipper plugin is required

The native Klipper Eddy module has two limitations that make the
above strategy impossible without instrumentation:

### Limitation 1 — paper test in the calibration loop

`PROBE_EDDY_CURRENT_CALIBRATE` opens an interactive `manual_probe`
session and waits for the user to type `ACCEPT` after performing a
paper test at the bed surface. There is no programmatic way to feed
that `ACCEPT` from a G-code macro reliably.

### Limitation 2 — calibration values do not activate in RAM

Both `_save_calibration` (frequency/Z table) and `_save_tap_threshold`
end with a single call to `configfile.set(...)`, which only writes to
the **pending SAVE_CONFIG** block. The runtime attributes
(`cal_freqs`, `cal_zpos`, `_tap_threshold`) are **not** updated.
Without a Klipper restart (which would interrupt the print), every
subsequent tap or scan continues to use the old, possibly inadequate
boot-time values.

The custom plugin
[`probe_eddy_auto_calibrate.py`](https://raw.githubusercontent.com/christianKEL/E5M-CK/refs/heads/main/files/probe_eddy_auto_calibrate.py)
addresses both limitations by direct instrumentation of the runtime
Python objects, without modifying any Klipper source file. The native
`probe_eddy_current.py` stays vanilla and survives Klipper updates.

## 4. The plugin in detail

The plugin registers three G-code commands.

### 4.1 `PROBE_EDDY_CALIBRATE_AUTO`

Reproduces the native frequency/Z calibration sequence, but uses the
**current toolhead position** as the Z=0 reference instead of the
interactive paper test. Builds a fake `ManualProbeResult` from the
current `(x, y, z)` and feeds it into `eddy_cal.post_manual_probe()`,
which then runs the standard 40 µm-step sweep up to ~4 mm.

Activates the resulting table in RAM by monkey-patching
`_save_calibration` for the duration of the call. The patched version
calls the original (which writes to pending SAVE_CONFIG) and then also
calls `eddy_cal.load_calibration()` to update `cal_freqs`/`cal_zpos`.

### 4.2 `EDDY_APPLY_TAP_THRESHOLD`

Activates a `tap_threshold` value in RAM after
`PROBE_EDDY_CURRENT_TAP_CALIBRATE TAP=verify`. Reads the value
from the pending SAVE_CONFIG (via
`configfile.get_status().save_config_pending_items`, **not** from
`settings`, which only reflects the boot-time content) and assigns
it directly to `eddy_tap._tap_threshold`.

### 4.3 `EDDY_RESET_TO_CONFIG`

Restores the runtime Eddy state to what was parsed from `printer.cfg`
at boot — the frequency/Z table and the `tap_threshold`. Used at the
start of every print to guarantee a deterministic starting state,
regardless of what manual operations were performed earlier in the
session. Does not reset `tap_z_offset` (immutable from config),
`calibration_temp` (read-only), or `reg_drive_current` (hardware-set
at boot).

## 5. Macros that orchestrate the plugin

### 5.1 `FULL_CALIBRATE`

Located in `macros_calibration.cfg`. Four steps:

1. **`PROBE_EDDY_CURRENT_TAP_CALIBRATE TAP=guess` / `refine` / `verify`**
   then **`EDDY_APPLY_TAP_THRESHOLD`** to make the new threshold
   active. The tap calibration is run **before** the table refresh
   because `TAP=guess` derives its threshold from the slope
   coefficients of the current table; refreshing the table first
   would change those coefficients and break `TAP=guess`.
2. **`SET_Z_FROM_PROBE METHOD=tap SAMPLES=5`** to locate kinematic
   Z=0 by tap impact, with median filtering.
3. **`PROBE_EDDY_CALIBRATE_AUTO`** to rebuild the frequency/Z table
   referenced on the freshly-located Z=0.
4. **`PROBE_ACCURACY_TAP SAMPLES=5`** to validate the result.

### 5.2 `FINAL_TAP_OFFSET`

Run after the final M109 to print temperature. Performs 3 taps and
applies the median as `SET_GCODE_OFFSET Z=` (absolute, not
incremental). Compensates for hotend thermal expansion between
calibration temperature (140 °C) and print temperature.

### 5.3 `EDDY_RESET_TO_CONFIG`

Called as the very first step of the start G-code, ensures we begin
each print from a clean, persisted state.

## 6. SSH installation procedure

The following steps assume:
- Klipper is running on a Creality K1/E5M-class board
- The config directory is `/usr/data/printer_data/config/`
- Klipper sources are at `/usr/data/klipper/`
- You have SSH access as `root`

If your installation differs (e.g. RPi running stock Klippermainline,
config at `~/printer_data/config/`), adjust the paths accordingly.

### 6.1 Install the plugin

```bash
# SSH into the printer
ssh root@<printer-ip>

# Download the plugin into Klipper's extras directory
cd /usr/data/klipper/klippy/extras/
wget https://raw.githubusercontent.com/christianKEL/E5M-CK/refs/heads/main/files/probe_eddy_auto_calibrate.py

# Verify download
ls -la probe_eddy_auto_calibrate.py

# Remove any previously cached .pyc that could shadow the new .py
# (Klipper compiles .py to .pyc; when you replace the .py, the .pyc
#  may still be loaded if its timestamp is newer.)
rm -f probe_eddy_auto_calibrate.pyc __pycache__/probe_eddy_auto_calibrate.*
```

> **Note**: every time you update the plugin (e.g. `wget` a new
> version), repeat the `rm -f` step. This is a common pitfall.

### 6.2 Register the plugin in `printer.cfg`

Add the following section to `/usr/data/printer_data/config/printer.cfg`,
typically near the top with other `[include]` and chip declarations:

```ini
[probe_eddy_auto_calibrate]
chip: btt_eddy
probe_speed: 5.0
z_ref_max: 0.5
```

The `chip` value must match your `[probe_eddy_current <name>]`
section name. `probe_speed` is the Z descend speed during calibration
(mm/s). `z_ref_max` caps the tolerated Z reference position to avoid
running auto-cal from a wrong height (the plugin will refuse to run
if Z > z_ref_max).

### 6.3 Required macro dependencies

The `FULL_CALIBRATE` macro depends on the following helpers, which
must be present in your config:

- **`SET_Z_FROM_PROBE`** (from `eddy.cfg`) — refines Z=0 with median
  filtering.
- **`PROBE_ACCURACY_TAP`** (from `eddy.cfg`) — accuracy validator
  with proper retract between samples (workaround for a Klipper bug
  where `samples_retract_dist=0` is hardcoded for tap method).

Both are provided in the
[`E5M-CK` repository](https://github.com/christianKEL/E5M-CK) under
`files/eddy.cfg`.

The `FULL_CALIBRATE` macro itself, `PREP_COLD`, and `FINAL_TAP_OFFSET`
are in `files/macros_calibration.cfg`.

### 6.4 Restart and verify

```bash
# In Klipper console (Fluidd/Mainsail) or via SSH curl:
FIRMWARE_RESTART
```

Check the boot-time log:

```bash
tail -50 /usr/data/printer_data/logs/klippy.log | grep -i eddy_auto
```

You should see no errors and the three commands should be available.
Test them:

```
EDDY_RESET_TO_CONFIG
```

Should respond with the table point count and the `tap_threshold`
value being applied to RAM.

## 7. Bootstrap state required

`FULL_CALIBRATE` is **not** a from-scratch calibrator. It expects an
already-bootstrapped Eddy probe with:

- `reg_drive_current` set (via `LDC_CALIBRATE_DRIVE_CURRENT`)
- `calibrate = ...` table present (via `PROBE_EDDY_CURRENT_CALIBRATE`)
- `tap_threshold = ...` set (via `PROBE_EDDY_CURRENT_TAP_CALIBRATE`)

These are produced by the standard Klipper bootstrap procedure
documented at https://www.klipper3d.org/Eddy_Probe.html and persisted
in the `#*# SAVE_CONFIG` block at the bottom of `printer.cfg`.

If those values are missing (e.g. fresh repo clone on a new machine),
`FULL_CALIBRATE` step 1 will fail with `insufficient slope delta`
because `TAP=guess` cannot derive a threshold without a calibration
table to read slope coefficients from.

For a from-scratch installation, follow the standard Klipper
procedure first, then use `FULL_CALIBRATE` for ongoing operation.

## 8. Typical start G-code structure

```gcode
EDDY_RESET_TO_CONFIG
SET_GCODE_OFFSET Z=0
BED_MESH_CLEAR

M140 S{first_layer_bed_temperature[0]}
M104 S140
M190 S{first_layer_bed_temperature[0]}
M109 S140

G4 P300000                  ; 5 min heat soak
G28                         ; scan-only Z homing
NOZZLE_CLEAR_ON_BRUSH       ; ends at 140 °C, heater off
M104 S140                   ; re-arm
M109 S140

FULL_CALIBRATE              ; ~4 min
BED_MESH_CALIBRATE METHOD=rapid_scan

NOZZLE_CLEAR_AT_PRINT_TEMP TEMP={first_layer_temperature[0]}
FINAL_TAP_OFFSET

; ... prime line + print ...
```

---

**Reference**: full source and current configuration files are
available at https://github.com/christianKEL/E5M-CK

— christianKEL, project *E5M-CK*

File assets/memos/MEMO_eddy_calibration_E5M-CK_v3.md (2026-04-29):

# MEMO — Calibration BTT Eddy USB sur Ender 5 Max + Klipper mainline

**Date :** 29 avril 2026 — version 3
**Machine :** Creality Ender 5 Max (CoreXY) + Nebula Pad (IP 192.168.1.94)
**Klipper :** mainline `v0.13.0-628-g373f200ca` (mars 2026)
**Sonde :** BTT Eddy USB (RP2040 + LDC1612)
**Serial :** `/dev/serial/by-id/usb-Klipper_rp2040_50445059303E9B1C-if00`
**Slicer :** OrcaSlicer (gcode_flavor : Marlin Legacy, arc_fitting OFF)

---

## ⚠️ RÈGLE D'OR ABSOLUE

> **AVANT TOUT TAP, ÉLOIGNER LA TÊTE DE 10 MM AU MINIMUM.**

Sans cette marge de 10 mm, le tap échoue avec `Unable to detect tap: insufficient slope delta`. Le LDC1612 a besoin d'une **baseline de fréquence stable** sur quelques millimètres avant de pouvoir détecter une variation au contact.

Cette règle est **systématiquement intégrée** dans :
- `homing.cfg` → `G1 Z10 F600` avant `SET_Z_FROM_PROBE METHOD=tap`
- Macro `SET_SCAN_FROM_TAP` → lift conditionnel `if Z<10 → G1 Z{10-current_z}`
- Macro `PROBE_ACCURACY_TAP` → setup à Z≥10 + retract de 3mm entre samples
- Toute commande manuelle `PROBE METHOD=tap` → précédée de `G0 Z10` ou `G1 Z10`

Aucune exception.

---

## 1. Contexte

L'Ender 5 Max stock utilise un fork Klipper Creality avec calibration Z par Nebula Pad propriétaire. Le projet E5M-CK migre vers **Klipper mainline pur** + sonde **BTT Eddy USB** pour bénéficier des fonctionnalités modernes : input shaper, bed mesh haute densité, fonctionnalité **TAP** thermal-independent.

### Évolution du mount Eddy

Le mount Eddy a été repositionné le 29/04/2026, passant de `(x=38, y=6)` à **`(x=22, y=0)`**. Cette modification a apporté un gain de précision majeur.

| Métrique | Mount initial (x=38, y=6) | **Mount actuel (x=22, y=0)** |
|---|---|---|
| Limite basse threshold | 26 | **14** (2× plus précis) |
| `tap_threshold` retenu | 50 | **28** |
| Z reporté à chaud | -0.121 mm | **+0.014 mm** (quasi-zéro flex) |
| Range PROBE_ACCURACY (10 samples) | 0.0089 mm | **0.0103 mm** |
| StdDev | 0.0031 mm | **0.0026 mm** |
| `tap_z_offset` requis | Oui (≈0.12) | **Non** |
| Drift scan↔tap @ chaud | ≈0.052 mm | ≈0.260 mm |

Le nouveau mount est **mécaniquement plus précis** (signal/bruit 2× meilleur, flex quasi-nul), au prix d'un drift thermique scan↔tap plus prononcé que la `drift_calibration` ne corrigeait avant. Solution adoptée : compensation dynamique à chaque print via `SET_SCAN_FROM_TAP`.

---

## 2. Découvertes critiques sur Klipper mainline

### 2.1 Bug Klipper #1 — `samp_retract_dist` hardcodé à 0 pour Eddy

Dans `klippy/extras/probe_eddy_current.py`, classe `EddyParameterHelper.get_probe_params()` (ligne 855) :

```python
if method not in ['scan', 'rapid_scan', 'tap']:
    return self._param_helper.get_probe_params(gcmd)
probe_speed = gcmd.get_float("PROBE_SPEED", 5.0, above=0.)
lift_speed = gcmd.get_float("LIFT_SPEED", 5.0, above=0.)
samples = gcmd.get_int("SAMPLES", 1, minval=1)
samp_retract_dist = 0.    # ← HARDCODÉ À 0
```

Pour les méthodes `scan`, `rapid_scan` et `tap`, `samp_retract_dist` est **hardcodé à 0**, ignorant à la fois la config et les paramètres runtime.

**Conséquence pratique** : `PROBE_ACCURACY METHOD=tap` échoue dès le 2e sample avec `Unable to detect tap: insufficient slope delta`. Le 1er tap réussit, mais le 2e démarre depuis la position de contact (sans lift), et la sonde voit une fréquence "déjà saturée" → erreur slope delta.

**Documenté officiellement** (Klipper Config_Changes 20260318) :
> *"The `[probe_eddy_current]` config options speed, lift_speed, samples, sample_retract_dist, samples_result, samples_tolerance, and samples_tolerance_retries no longer apply to probe commands using METHOD=scan, METHOD=rapid_scan, nor METHOD=tap."*

Mais même les paramètres runtime ne fonctionnent pas pour le retract sur tap. Bug de cohérence interne Klipper.

**Workaround** : macro custom `PROBE_ACCURACY_TAP` qui réimplémente la boucle multi-sample avec lift correct entre chaque tap (voir section 5).

### 2.2 Bug Klipper #2 — `SET_GCODE_OFFSET Z_ADJUST=` cumule entre appels

Le paramètre `Z_ADJUST=` est **incrémental** : il s'ajoute à `gcode_offset.z` actuel. Plusieurs appels successifs de `SET_SCAN_FROM_TAP` cumulaient les offsets :

- Appel 1 : drift=0.230 → Z_ADJUST=-0.230 → gcode_offset.z = -0.230
- Appel 2 : drift=0.235 → Z_ADJUST=-0.235 → gcode_offset.z = **-0.465** ❌ (au lieu de -0.235)

**Solution** : utiliser `Z=` (absolu) au lieu de `Z_ADJUST=` (relatif) dans `_ADJ_SCAN_FROM_TAP`. Une seule commande remplace la valeur courante.

### 2.3 Tap échoue si Z trop bas

Si on lance un tap depuis une position Z < ≈5-8 mm, Klipper ne peut pas mesurer un slope delta clair → `insufficient slope delta`. La règle d'or **lift 10mm avant tap** résout ce problème de manière définitive.

### 2.4 Calibration height map à refaire après remount

Après changement physique du mount Eddy, la calibration height map (`PROBE_EDDY_CURRENT_CALIBRATE`) doit être refaite. La table fréquence ↔ Z est spécifique à la position physique de la coil par rapport au bed.

### 2.5 PROBE_ACCURACY METHOD=tap est cassé

Pour les raisons décrites en 2.1, **`PROBE_ACCURACY METHOD=tap` ne fonctionne pas**. Klipper affiche le 1er résultat puis échoue avec `insufficient slope delta` sur les samples suivants.

→ Toujours utiliser la macro custom **`PROBE_ACCURACY_TAP`**.

### 2.6 PR Klipper référencées

- **PR #7186** (open) — `temperature_probe: use tap for calibration`
- **PR #7179** (closed) — fournit le pattern `SET_SCAN_FROM_TAP`
- **PR #7220** (mergé) — ajoute l'option `tap_z_offset` (non utilisée dans notre setup)

---

## 3. Configuration finale `eddy.cfg`

```ini
# ═══════════════════════════════════════════════════════
# BTT Eddy USB — Klipper mainline configuration
# Aligned with OFFICIAL Klipper documentation + PR #7179
# https://www.klipper3d.org/Eddy_Probe.html
# ═══════════════════════════════════════════════════════

[mcu eddy]
serial: /dev/serial/by-id/usb-Klipper_rp2040_50445059303E9B1C-if00
restart_method: command

[temperature_sensor btt_eddy_mcu]
sensor_type: temperature_mcu
sensor_mcu: eddy
min_temp: 10
max_temp: 100

[probe_eddy_current btt_eddy]
sensor_type: ldc1612
descend_z: 0.5
i2c_mcu: eddy
i2c_bus: i2c0f
x_offset: 22.0
y_offset: 0.0
# Tap parameters — populated after PROBE_EDDY_CURRENT_CALIBRATE @ hot
tap_threshold: 28
# Note Klipper Config_Changes 20260318: samples/sample_retract_dist/etc.
# en config N'APPLIQUENT PAS pour scan/rapid_scan/tap. Passer en runtime
# sur la commande PROBE.

[temperature_probe btt_eddy]
sensor_type: Generic 3950
sensor_pin: eddy:gpio26
horizontal_move_z: 2

# ─── OFFICIAL KLIPPER HOMING CORRECTION MACROS ───
# https://www.klipper3d.org/Eddy_Probe.html#homing-correction-macros

[gcode_macro _RELOAD_Z_OFFSET_FROM_PROBE]
gcode:
    {% set Z = printer.toolhead.position.z %}
    SET_KINEMATIC_POSITION Z={Z - printer.probe.last_probe_position.z}

[gcode_macro SET_Z_FROM_PROBE]
description: Refine Z=0 with a probe (use METHOD=tap for thermal-independent reference)
gcode:
    {% set METHOD = params.METHOD | default("automatic") %}
    PROBE METHOD={METHOD}
    _RELOAD_Z_OFFSET_FROM_PROBE
    G0 Z5

# ─── TAP-THEN-SCAN PATTERN (PR #7179) ───
# Allows bed_mesh in scan mode to be thermally-compensated by tap
# Usage in start G-code:
#   SET_SCAN_FROM_TAP
#   BED_MESH_CALIBRATE ADAPTIVE=1 METHOD=rapid_scan HORIZONTAL_MOVE_Z=<descend_z>

[gcode_macro _ADJ_SCAN_FROM_TAP]
description: Internal helper — applies absolute Z gcode offset = -drift
gcode:
    {% set OFFSET = printer.probe.last_probe_position.z %}
    {% set probe_temp = printer["temperature_probe btt_eddy"].temperature %}
    RESPOND TYPE=command MSG="Scan-from-tap : drift={OFFSET|round(4)} mm @ coil={probe_temp|round(1)}°C"
    # Use Z= (absolute) instead of Z_ADJUST= (relative) to avoid accumulation
    SET_GCODE_OFFSET Z={(-OFFSET)}

[gcode_macro SET_SCAN_FROM_TAP]
description: Tap-then-scan : Z précis (1 tap) + référence mesh thermiquement compensée (scan median 5x)
gcode:
    # MANDATORY: always lift Z to 10mm before tap (avoid "insufficient slope delta")
    {% set current_z = printer.toolhead.position.z|float %}
    {% if current_z < 10 %}
        G91
        G1 Z{10 - current_z} F600
        G90
    {% endif %}
    # Tap = 1 sample (multi-sample tap broken by Klipper bug)
    SET_Z_FROM_PROBE METHOD=tap
    {% set is_absolute = printer.gcode_move.absolute_coordinates %}
    G90
    {% set cf = printer.configfile.settings %}
    {% set eddy = cf["probe_eddy_current btt_eddy"] %}
    {% set amap = printer.gcode_move.axis_map %}
    {% set tpos = printer.gcode_move.position %}
    G0 Z5 F300
    G0 X{tpos[amap["X"]] - eddy.x_offset} Y{tpos[amap["Y"]] - eddy.y_offset} F3000
    M400
    G4 P200
    G0 Z{eddy.descend_z} F300
    M400
    G4 P200
    # Scan multi-sample works (no retract needed since scan stays at fixed Z)
    PROBE METHOD=scan SAMPLES=5 SAMPLES_RESULT=median
    _ADJ_SCAN_FROM_TAP
    G0 Z5 F600
    {% if not is_absolute %}
        G91
    {% endif %}
```

### Points clés de la config

| Paramètre | Valeur | Justification |
|---|---|---|
| `descend_z` | 0.5 | Hauteur scan référence (PR #7179 recommandation) |
| `x_offset` / `y_offset` | 22.0 / 0.0 | Mount actuel |
| `tap_threshold` | 28 | Calibré : limite basse 14 × 2 |
| `tap_z_offset` | absent | Mount précis = pas de flex à compenser |
| `temperature_probe.horizontal_move_z` | 2 | Hauteur sécurité pour mesh, non critique |
| `samples`, `sample_retract_dist` | absents de config | Ignorés depuis Klipper 20260318 |
| `M400 + G4 P200` autour de Z | présents | Stabilise le sensor avant lecture |

---

## 4. Configuration `homing.cfg`

```ini
[homing_override]
axes: xyz
set_position_z: 0
gcode:
    G90
    {% set home_all = 'X' not in params and 'Y' not in params and 'Z' not in params %}
    G1 Z30 F600
    {% if home_all or 'X' in params or 'Y' in params %}
        G28 Y
        G1 Y400 F2400
    {% endif %}
    {% if home_all or 'X' in params %}
        G28 X
        G1 X380 F2400
    {% endif %}
    {% if home_all or 'Z' in params %}
        G0 X200 Y200 F6000
        G28 Z                          # rough Z homing via Eddy virtual_endstop
        G1 Z10 F600                    # MANDATORY: lift to 10mm before tap
        SET_Z_FROM_PROBE METHOD=tap    # precise Z=0 refinement via TAP
    {% endif %}
```

Le `G1 Z10 F600` **avant** le tap est obligatoire. Sans cette montée, le tap échoue.

---

## 5. Macro `PROBE_ACCURACY_TAP` (workaround bug Klipper)

Cette macro custom contourne le bug Klipper qui rend `PROBE_ACCURACY METHOD=tap` inutilisable. Elle réimplémente la boucle multi-sample avec lift correct entre chaque tap, et calcule les statistiques.

### Localisation

`/usr/data/printer_data/config/macros_E5M_CK.cfg`

### Code

```ini
[gcode_macro PROBE_ACCURACY_TAP]
description: Wrapper around PROBE METHOD=tap with proper retract between samples (workaround Klipper bug ligne 855 probe_eddy_current.py)
variable_samples_data: []
variable_samples_sq_sum: 0.0
gcode:
    {% set samples = params.SAMPLES|default(10)|int %}
    {% set retract = params.SAMPLE_RETRACT_DIST|default(3)|float %}
    {% set tap_threshold = params.TAP_THRESHOLD|default(0)|int %}
    {% set lift_speed = params.LIFT_SPEED|default(5)|float %}

    {% set xpos = printer.toolhead.position.x|float %}
    {% set ypos = printer.toolhead.position.y|float %}
    {% set zpos = printer.toolhead.position.z|float %}

    RESPOND TYPE=command MSG="PROBE_ACCURACY_TAP at X:{xpos|round(3)} Y:{ypos|round(3)} Z:{zpos|round(3)}"
    RESPOND TYPE=command MSG="  (samples={samples} retract={retract} threshold={tap_threshold if tap_threshold > 0 else 'config'})"

    SET_GCODE_VARIABLE MACRO=PROBE_ACCURACY_TAP VARIABLE=samples_data VALUE="[]"
    SET_GCODE_VARIABLE MACRO=PROBE_ACCURACY_TAP VARIABLE=samples_sq_sum VALUE=0.0

    {% for i in range(samples) %}
        G91
        G0 Z{retract} F{lift_speed * 60}
        G90
        {% if tap_threshold > 0 %}
            PROBE METHOD=tap TAP_THRESHOLD={tap_threshold}
        {% else %}
            PROBE METHOD=tap
        {% endif %}
        _PROBE_ACCURACY_TAP_RECORD
    {% endfor %}

    G91
    G0 Z{retract} F{lift_speed * 60}
    G90

    _PROBE_ACCURACY_TAP_REPORT

[gcode_macro _PROBE_ACCURACY_TAP_RECORD]
description: Internal helper for PROBE_ACCURACY_TAP - records last z and accumulates squared sum
gcode:
    {% set last_z = printer.probe.last_z_result|float %}
    {% set existing = printer["gcode_macro PROBE_ACCURACY_TAP"].samples_data %}
    {% set new_data = existing + [last_z] %}
    {% set old_sq = printer["gcode_macro PROBE_ACCURACY_TAP"].samples_sq_sum|float %}
    {% set new_sq = old_sq + last_z * last_z %}
    SET_GCODE_VARIABLE MACRO=PROBE_ACCURACY_TAP VARIABLE=samples_data VALUE="{new_data}"
    SET_GCODE_VARIABLE MACRO=PROBE_ACCURACY_TAP VARIABLE=samples_sq_sum VALUE={new_sq}

[gcode_macro _PROBE_ACCURACY_TAP_REPORT]
description: Internal helper for PROBE_ACCURACY_TAP - computes and reports stats
gcode:
    {% set data = printer["gcode_macro PROBE_ACCURACY_TAP"].samples_data %}
    {% set sum_sq = printer["gcode_macro PROBE_ACCURACY_TAP"].samples_sq_sum|float %}
    {% set n = data|length %}
    {% if n < 1 %}
        RESPOND TYPE=error MSG="PROBE_ACCURACY_TAP: no samples collected"
    {% else %}
        {% set mn = data|min %}
        {% set mx = data|max %}
        {% set rng = mx - mn %}
        {% set avg = (data|sum) / n %}
        {% set variance = (sum_sq / n) - (avg * avg) %}
        {% set stddev = variance ** 0.5 if variance > 0 else 0 %}
        {% set sorted_data = data|sort %}
        {% if n % 2 == 1 %}
            {% set median = sorted_data[(n - 1) // 2] %}
        {% else %}
            {% set median = (sorted_data[n // 2 - 1] + sorted_data[n // 2]) / 2 %}
        {% endif %}
        RESPOND TYPE=command MSG="probe accuracy results: maximum {'%.6f' % mx}, minimum {'%.6f' % mn}, range {'%.6f' % rng}, average {'%.6f' % avg}, median {'%.6f' % median}, standard deviation {'%.6f' % stddev}"
    {% endif %}
```

### Notes d'implémentation

- **Variance via formule à une passe** : `Var = E[X²] - E[X]²`. Évite le besoin d'une boucle accumulator (le `namespace` Jinja n'est pas disponible dans Klipper sandbox).
- **`SET_GCODE_VARIABLE`** pour stocker `samples_data` (liste) et `samples_sq_sum` (somme des carrés). Permet d'accumuler à chaque sample sans namespace.
- **Compatible PROBE_ACCURACY** : même format de sortie pour interopérabilité.

### Usage

```
# Setup obligatoire avant
G28
G1 X200 Y200 F6000
G1 Z10 F600                                  # ← LIFT 10mm AVANT TAP
SET_KINEMATIC_POSITION X=200 Y=200 Z=10

# Lancement
PROBE_ACCURACY_TAP                           # défaut: SAMPLES=10
PROBE_ACCURACY_TAP SAMPLES=5                 # plus rapide
PROBE_ACCURACY_TAP SAMPLES=20 TAP_THRESHOLD=30   # paramètres runtime
```

### Sortie type

```
PROBE_ACCURACY_TAP at X:200.000 Y:200.000 Z:5.000
  (samples=10 retract=3.0 threshold=config)
probe: at 200.000,200.000 bed will contact at z=0.001
... (10 lignes similaires)
probe accuracy results: maximum 0.001817, minimum -0.005905, range 0.007722, average -0.001651, median -0.001786, standard deviation 0.002766
```

---

## 6. Procédure de calibration complète

### Pré-requis avant chaque calibration

- Bed et nozzle propres (pas de plastique)
- `NOZZLE_CLEAR_ON_BRUSH` exécuté si possible
- Stable thermiquement (5 min d'homogénéisation après cible atteinte)
- **Tête au moins à 10 mm avant chaque tap**

### Étape 1 — `LDC_CALIBRATE_DRIVE_CURRENT` (à froid, 1 fois après remount)

Calibre l'amplitude du signal du capteur LDC1612.

```
G28
G0 X200 Y200 F6000
G1 Z20 F600
LDC_CALIBRATE_DRIVE_CURRENT CHIP=btt_eddy
SAVE_CONFIG
```

Klipper redémarre. Résultat actuel : `reg_drive_current = 15`.

### Étape 2 — Préchauffe + homogénéisation thermique

```
M140 S65
M104 S150
TEMPERATURE_WAIT SENSOR=heater_bed MINIMUM=64
TEMPERATURE_WAIT SENSOR=extruder MINIMUM=148
G4 P30000        # 30s minimum, 5min recommandé pour grand bed
```

### Étape 3 — Calibration height map à chaud (`PROBE_EDDY_CURRENT_CALIBRATE`)

```
G1 X200 Y200 F6000
G1 Z30 F600
SET_KINEMATIC_POSITION Z=200    # trick pour mouvements Z manuels
```

Paper test manuel via Fluidd (flèches Z par pas de 0.1 mm) jusqu'au drag léger du papier. Puis :

```
SET_KINEMATIC_POSITION Z=0
G1 Z1 F300
PROBE_EDDY_CURRENT_CALIBRATE CHIP=btt_eddy
```

Suivre les invites interactives (`TESTZ Z=-0.1`, `ACCEPT` quand drag OK). Klipper balaye sur ~3 minutes.

```
SAVE_CONFIG
```

Résultat actuel à 45.5°C coil : `Total freq range: 47268.777 Hz`, `Global MAD_Hz: 17.612`.

### Étape 4 — Calibration `tap_threshold` par bracketing

C'est la méthode officielle Klipper. On commence haut, on descend par paliers, et on identifie la **limite basse** où le tap commence à échouer (sous le bruit).

#### Setup obligatoire

```
G28
G1 X200 Y200 F6000
G1 Z10 F600                              # ← LIFT 10mm OBLIGATOIRE
SET_KINEMATIC_POSITION X=200 Y=200 Z=10
G0 Z5
```

#### Bracketing (entre chaque test, lift Z à 5mm minimum)

```
PROBE METHOD=tap TAP_THRESHOLD=80
G0 Z5
PROBE METHOD=tap TAP_THRESHOLD=50
G0 Z5
PROBE METHOD=tap TAP_THRESHOLD=30
G0 Z5
PROBE METHOD=tap TAP_THRESHOLD=20
G0 Z5
PROBE METHOD=tap TAP_THRESHOLD=15
G0 Z5
PROBE METHOD=tap TAP_THRESHOLD=12
```

⚠️ Le `G0 Z5` entre chaque PROBE est essentiel : sans lift, le 2e PROBE part de la position de contact et échoue avec `insufficient slope delta` (même bug que PROBE_ACCURACY).

#### Identifier la limite basse

À un moment, le tap arrête de détecter avec `Unable to detect tap: insufficient slope delta`. La **valeur juste au-dessus** du fail est la limite basse.

**Bracketing actuel (mount x=22, y=0)** :
- Threshold 12 → fail
- Threshold 13 → fail
- **Threshold 14 → détecte z=+0.014** ← limite basse

#### Choisir tap_threshold

**Règle de pouce officielle Klipper** : `tap_threshold = limite_basse × 2`.

→ `14 × 2 = 28` → **`tap_threshold = 28`** retenu.

### Étape 5 — Validation par `PROBE_ACCURACY_TAP`

```
G28
G1 X200 Y200 F6000
G1 Z10 F600                              # ← LIFT 10mm OBLIGATOIRE
SET_KINEMATIC_POSITION X=200 Y=200 Z=10
G0 Z5
PROBE_ACCURACY_TAP SAMPLES=10
```

Résultats actuels (mount x=22 y=0, threshold=28, à froid) :

```
samples=10  retract=3.0  threshold=config
range:    0.0103 mm    ← cible Klipper <0.020 mm, 2× mieux
stddev:   0.0026 mm    ← excellent (2.6 microns)
average:  +0.0554 mm
median:   +0.0548 mm
```

Verdict : **précision ±5 microns tap-à-tap**. Calibration validée.

### Étape 6 — Persister `tap_threshold` dans `eddy.cfg`

```bash
sed -i 's|^tap_threshold:.*|tap_threshold: 28|' /usr/data/printer_data/config/eddy.cfg
/etc/init.d/S55klipper_service restart
```

### Étape 7 — Test `SET_SCAN_FROM_TAP`

```
G28
G1 X200 Y200 F6000
SET_SCAN_FROM_TAP
```

La macro lift automatiquement à 10mm si nécessaire (règle d'or intégrée).

Résultat type (à froid, coil ≈35°C) :

```
probe: at 200.000,200.000 bed will contact at z=-0.001332    ← TAP @ centre
Result: at 200.003,200.001 estimate contact at z=0.260722    ← SCAN au point corrigé via x/y_offset
Scan-from-tap : drift=0.2607 mm @ coil=34.6°C
```

→ Macro applique automatiquement `SET_GCODE_OFFSET Z=-0.2607` pour compenser le drift thermique scan↔tap.

### Étape 8 — Validation non-cumul de l'offset

```
SET_SCAN_FROM_TAP
SET_SCAN_FROM_TAP
```

Les 2 appels successifs doivent reporter un drift **similaire** (≈0.26mm) et l'offset gcode appliqué doit rester ≈-0.26mm (pas se cumuler à -0.52mm).

Vérifier avec :

```
GET_POSITION
```

Cherche la ligne `gcode:` dans la sortie. Le Z affiché reflète l'offset gcode courant.

---

## 7. Stratégie de compensation thermique

### Choix d'architecture

`temperature_probe.drift_calibration` a été **supprimée** (c'était une calibration de l'ancien mount, devenue obsolète). Elle n'a pas été refaite après le remount.

**Stratégie adoptée** : compensation dynamique à chaque print via `SET_SCAN_FROM_TAP` dans le start G-code.

### Workflow par print

1. `SET_Z_FROM_PROBE METHOD=tap` (via G28 ou explicite) → Z=0 = position physique du tap
2. `SET_SCAN_FROM_TAP` → calcule le delta scan↔tap à la température courante, applique `SET_GCODE_OFFSET Z=` correspondant
3. `BED_MESH_CALIBRATE METHOD=rapid_scan` → mesh à `descend_z=0.5mm`, thermiquement compensé via l'offset

### Avantages

- Compensation **toujours actuelle** (à la température exacte du print)
- Pas dépendant d'une calibration drift figée qui peut dériver
- Robuste face aux changements de mount, plaque, filament
- Le drift de 0.26mm à 35°C n'est **pas un problème** : il est compensé en live

### Contreparties

- Un peu plus long au start G-code (+5s)
- Si la coil chauffe encore pendant le print (bed rayonne), le drift change → le mesh appliqué au début peut dériver. Mitigation : `bed_mesh fade_start: 1.0 / fade_end: 20 / fade_target: 0` permet à l'effet du mesh de s'estomper en altitude.

### À long terme

Si le drift résiduel devient gênant, refaire `temperature_probe drift_calibration` à chaud :

```
TEMPERATURE_PROBE_CALIBRATE PROBE=btt_eddy TARGET=55
```

Procédure interactive ~30 min. À considérer si la qualité dévie sur les hauteurs élevées (Z > 20 mm).

---

## 8. Bed mesh — configuration finale

```ini
[bed_mesh]
horizontal_move_z: 2
scan_overshoot: 8
speed: 200
mesh_min: 30.0, 15.0
mesh_max: 391.0, 391.0
probe_count: 25, 25
fade_start: 1.0
fade_end: 20
fade_target: 0
mesh_pps: 4, 4
algorithm: bicubic
bicubic_tension: 0.2
```

### Calcul des limites mesh (formule officielle Klipper)

Avec `x_offset=22, y_offset=0` et `scan_overshoot=8` :

| Limite | Formule | Résultat |
|---|---|---|
| `mesh_min_x` | `max(15, x_offset + scan_overshoot) = max(15, 30)` | **30** |
| `mesh_min_y` | `max(15, y_offset + scan_overshoot) = max(15, 8)` | **15** |
| `mesh_max_x` | `bed_max - scan_overshoot - margin = 400 - 8 - 1` | **391** |
| `mesh_max_y` | idem | **391** (gain en Y vs ancien mount) |

### Choix `horizontal_move_z = 2`

Sécurité contre collisions (bed warp, objet sur plateau). PR #7179 recommande 0.5mm pour précision max, mais 2mm est un compromis sécurité acceptable. Le tap reste la référence Z=0 absolue.

### Méthode pour bed mesh pendant un print

`BED_MESH_CALIBRATE METHOD=rapid_scan ADAPTIVE=1` est recommandé :
- `rapid_scan` : balayage continu, ~30s pour un mesh complet (vs ~3 min en `scan` point-par-point)
- `ADAPTIVE=1` : ne mesh que la zone d'impression effective, encore plus rapide

⚠️ Toujours appeler `SET_SCAN_FROM_TAP` **avant** le mesh pour compensation thermique.

---

## 9. Crashes stepcompress — diagnostic et résolution

### Symptômes

```
b'stepcompress o=8 i=-26264 c=1 a=0: Invalid sequence'
b"Error in syncemitter 'stepper_y' step generation"
Exception in flush_handler
Internal error in stepcompress
Transition to shutdown state
```

Crashe pendant un print, parfois après plusieurs heures, sur stepper_x ou stepper_y (CoreXY). Indépendant du MCU (qui n'est pas saturé).

### Cause #1 (majeure) — `arc_fitting` activé dans Orca

Avec `arc_fitting = 1` dans Orca, le slicer génère des G2/G3 partout, y compris **micro-arcs** sur les courbes de support et bridges. Sur un G-code de 3h17 analysé :

| Métrique | Valeur |
|---|---|
| Total arcs G2+G3 | 49 816 |
| Arcs avec rayon < 1 mm | **3 105** |
| Arcs avec rayon 1-2 mm | 5 661 |
| Plus petit rayon | **0.020 mm** (20 microns) |

Klipper a `[gcode_arcs] resolution: 1.0` par défaut. Pour un arc de rayon 0.02mm, la formule `segments = floor(flat_mm / resolution)` donne 0 → fallback à 1 segment droit dégénéré → mouvement pathologique pour stepcompress + input_shaper.

**Position officielle Klipper** (article Knowledge Base "The Myth of G2/G3 Arc Commands", juillet 2025, par Sineos) :

> *"Using arc commands (G2 / G3) in Klipper provides no significant real-world benefit for print quality, motion smoothness, or printer performance. Instead, it adds two further approximation steps, increasing the potential error."*

→ **Solution : désactiver `arc_fitting` dans Orca.**
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

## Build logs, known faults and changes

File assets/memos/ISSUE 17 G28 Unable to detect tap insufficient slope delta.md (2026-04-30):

─────────────────────────────────────────────────────────
MEMO — Issue #17 : "Unable to detect tap: insufficient slope delta"
Project    : E5M-CK
File       : homing.cfg
─────────────────────────────────────────────────────────

PROBLEM
The first G28 after a Klipper restart consistently failed at the
Z refinement step with repeated "insufficient slope delta" errors.
Root cause : the original homing sequence performed the Z=0
refinement via tap, but at that point the nozzle still carried
residue from the previous print (no nozzle clean is possible
before the first home). A dirty nozzle dampens the tap signal
below the slope-detection threshold, so the tap aborts.

SOLUTION
Branch the Z=0 refinement on the actual homing state of the Z
axis at the moment G28 is invoked :

  • Z not yet homed  → SET_Z_FROM_PROBE METHOD=scan
                       (no contact, dirty nozzle is irrelevant)
  • Z already homed  → SET_Z_FROM_PROBE METHOD=tap
                       (5-sample median, original behaviour)

This means the very first home of the session always uses scan,
and any subsequent G28 in the same session keeps the tap
precision. The tap-based precision needed for the actual print
is still provided downstream by SET_SCAN_FROM_TAP in the start
G-code, executed AFTER NOZZLE_CLEAR_ON_BRUSH.

IMPLEMENTATION DETAIL
The 'set_position_z: 0' option of [homing_override] had to be
removed. Klipper applies set_position_z BEFORE the gcode template
runs and marks the axis as homed in the process, so the
'z in printer.toolhead.homed_axes' check would always be true and
the branching would never trigger. The unconditional Z=0 fake-home
was replaced with a conditional SET_KINEMATIC_POSITION Z=0 that
only fires when Z is actually unhomed.

KNOWN LIMITATION
A manual G28 issued after CAL_BED_Z_TILT (which leaves Z unhomed
and bed dropped) will correctly trigger the scan branch — good.
However, a G28 issued mid-session with a dirty nozzle (rare case)
will still attempt tap. Workaround : run FIRMWARE_RESTART first.

─────────────────────────────────────────────────────────
                                                  — E5M-CK
─────────────────────────────────────────────────────────

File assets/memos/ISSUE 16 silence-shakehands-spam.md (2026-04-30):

# Silencing Creality `master-server` `shakehands` Spam in `klippy.log`

> **E5M-CK** — Ender 5 Max + Creality + Klipper mainline configuration project.

A minimal, fully reversible fix for Creality printers running mainline
Klipper (Ender 5 Max, K1 family, and similar Creality F006-based firmware).

## The Problem

On Creality printers running mainline Klipper, `klippy.log` is flooded
with the following message about once per second:

```
webhooks: No registered callback for path 'shakehands'
```

The log fills up quickly, drowning out useful diagnostic output and
making it harder to debug real issues.

## Root Cause

The Creality stock firmware ships a proprietary userland that includes a
process called `master-server` (`/usr/bin/master-server`). It is the
orchestrator that bridges the Creality touchscreen UI, the Creality
cloud services, and the printer's motion control daemon.

`master-server` opens a Unix socket connection to Klipper at
`/tmp/klippy_uds` and periodically polls a webhook endpoint named
`shakehands` (a typo for "shake_hands"). That endpoint exists only in
Creality's forked Klipper — **mainline Klipper has no such handler**, so
it logs an error every time the request arrives.

Identifying the culprit can be done with `lsof`:

```sh
lsof /tmp/klippy_uds
```

The connection from `/usr/bin/master-server` is the offending one. Its
peer socket is registered under the unusual name `/tmp/klippy_client`,
visible in `/proc/net/unix`.

## What `master-server` Provides (and What You Lose)

Disabling `master-server` removes:

- The Creality Cloud / Creality Print mobile app integration
- Control from the **stock Creality touchscreen UI** (irrelevant if you
  use GuppyScreen, Mainsail, or Fluidd)
- Automatic cloud upload and notifications

It does **not** affect:

- Klipper, Moonraker, Fluidd, Mainsail
- GuppyScreen
- The camera stack (`webrtc`)
- Wi-Fi, SSH, NTP
- Klipper macros and configurations

If you are running a mainline-Klipper setup with a third-party UI, you
were almost certainly not using any `master-server` features anyway.

## The Fix

The approach is to leave the original Creality init scripts **untouched**
and add a second init script that kills `master-server` shortly after
boot. This is the most reversible option: removing the file restores the
system to its factory state.

### Installation

Create the script at `/etc/init.d/Z99kill_master_server`:

```sh
cat > /etc/init.d/Z99kill_master_server << 'EOF'
#!/bin/sh
case "$1" in
    start)
        ( sleep 8 && killall master-server 2>/dev/null ) &
        ;;
esac
exit 0
EOF
chmod +x /etc/init.d/Z99kill_master_server
```

Then reboot the printer.

### How It Works

- `Z99kill_master_server` runs at boot. Its name guarantees it executes
  alphabetically after `S99start_app`, the Creality script that spawns
  `master-server`.
- The 8-second `sleep` is a safety margin in case the Creality init
  scripts run in parallel rather than strictly sequentially. After
  8 seconds `master-server` is reliably running and ready to be killed.
- `killall master-server` terminates only that process. All other
  Creality services (`audio-server`, `wifi-server`, `app-server`,
  `web-server`, `upgrade-server`) keep running.
- Klipper's `Disconnected` notice for the closed socket is logged once,
  and the `shakehands` spam stops permanently.

### Verification

About 30 seconds after boot:

```sh
ps w | grep master-server | grep -v grep
```

The output should be empty. You can also check the live log:

```sh
tail -f /usr/data/printer_data/logs/klippy.log
```

There should be no further `shakehands` lines.

### Reverting

```sh
rm /etc/init.d/Z99kill_master_server
reboot
```

The system returns to its original Creality behavior. No backup of any
stock file is required, because no stock file was modified.

## Tested On

- Ender 5 Max (mainboard CR4NS200323C10) running mainline Klipper +
  Moonraker + Fluidd + GuppyScreen
- Should apply unmodified to any Creality printer using the F006
  userland that runs `master-server` from `/etc/init.d/S99start_app`,
  including K1 variants flashed to mainline Klipper.

## License

Public domain. Use, copy, modify freely.

---

*Part of the **E5M-CK** configuration project — Ender 5 Max running
mainline Klipper, BTT Eddy probe, GuppyScreen, and Fluidd on the stock
Creality F006 mainboard (CR4NS200323C10).*

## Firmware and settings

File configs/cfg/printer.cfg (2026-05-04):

# Version: v1.2.10
# ═══════════════════════════════════════════════════════
# E5M-CK — printer.cfg
# Ender 5 Max + BTT Eddy + Klipper mainline
# Mainboard : CR4NS200323C10 (GD32F303RET6)
# Nozzle MCU : CR-NOZZLE_V21 (GD32F303CBT6)
# ═══════════════════════════════════════════════════════

[include macros_calibration.cfg]
[include macros_E5M_CK.cfg]
[include GuppyScreen/*.cfg]
[include eddy.cfg]
[include homing.cfg]
[include gcode_macro.cfg]
# ADXL345 disabled : nozzle MCU firmware (Creality 2023) incompatible
# with Klipper mainline ADXL driver. See repo issue 05.


# ─── MCUs ───
[mcu]
serial: /dev/ttyS1
baud: 230400
restart_method: command

[mcu nozzle_mcu]
serial: /dev/ttyS7
baud: 230400
restart_method: command

[force_move]
enable_force_move: True


# ─── Heaters safety ───
[verify_heater extruder]

[verify_heater heater_bed]
check_gain_time: 120
heating_gain: 1.0
hysteresis: 10


# ─── Input shaper ───
[input_shaper]
shaper_type_x: zv
shaper_freq_x: 50.6
shaper_type_y: mzv
shaper_freq_y: 41.8


# ─── Printer kinematics ───
[printer]
kinematics: corexy
max_velocity: 1000
max_accel: 6500
minimum_cruise_ratio: 0.5
max_z_velocity: 30
square_corner_velocity: 5.0
max_z_accel: 300

[idle_timeout]
timeout: 99999999


# ─── Steppers ───
[stepper_x]
step_pulse_duration: 0.000000501
step_pin: PC2
dir_pin: !PB9
enable_pin: !PC3
microsteps: 32
rotation_distance: 63.874
endstop_pin: !PA11
position_endstop: 400.5
position_min: -5
position_max: 406
homing_speed: 40
homing_retract_dist: 0

[tmc2209 stepper_x]
uart_pin: PB12
uart_address: 3
interpolate: True
run_current: 2.0
sense_resistor: 0.150
stealthchop_threshold: 0
diag_pin: ^PB10
driver_SGTHRS: 80

[stepper_y]
step_pulse_duration: 0.000000501
step_pin: PB8
dir_pin: PB7
enable_pin: !PC3
microsteps: 32
rotation_distance: 64.024
endstop_pin: !PA12
position_endstop: 401
position_min: -1
position_max: 401
homing_speed: 40
homing_retract_dist: 0

[tmc2209 stepper_y]
uart_pin: PB13
uart_address: 3
interpolate: True
run_current: 2.0
sense_resistor: 0.150
stealthchop_threshold: 0
diag_pin: ^PB11
driver_SGTHRS: 80

[stepper_z]
step_pulse_duration: 0.000000501
step_pin: PB6
dir_pin: PB5
enable_pin: !PC3
microsteps: 32
rotation_distance: 3.9930
gear_ratio: 1:1
endstop_pin: probe:z_virtual_endstop
homing_retract_dist: 0
position_max: 406.5
position_min: -2

[tmc2209 stepper_z]
uart_pin: PB14
uart_address: 3
interpolate: True
run_current: 0.8
sense_resistor: 0.150
stealthchop_threshold: 0
diag_pin: PB0


# ─── Filament runout sensor ───
[filament_switch_sensor filament_sensor]
switch_pin: !PC6
pause_on_runout: true


# ─── Extruder ───
[extruder]
step_pulse_duration: 0.000000501
max_extrude_only_distance: 1000
max_extrude_cross_section: 80
pressure_advance = 0.04
step_pin: nozzle_mcu: PB5
dir_pin: nozzle_mcu: PB4
enable_pin: !nozzle_mcu: PB2
microsteps: 16
rotation_distance: 6.72
nozzle_diameter: 0.400
filament_diameter: 1.750
heater_pin: nozzle_mcu: PB8
sensor_type: EPCOS 100K B57560G104F
sensor_pin: nozzle_mcu: PA0
control = pid
pid_kp = 20.145
pid_ki = 1.919
pid_kd = 52.881
min_temp: 0
max_temp: 320

[tmc2209 extruder]
uart_pin: nozzle_mcu: PB10
uart_address: 3
run_current: 0.6
sense_resistor: 0.15
stealthchop_threshold: 0


# ─── Heated bed ───
[heater_bed]
pwm_cycle_time: 0.3
heater_pin: PA4
sensor_type: EPCOS 100K B57560G104F
sensor_pin: PC4
pwm_cycle_time: 0.3
control = pid
pid_kp = 30
pid_ki = 0.075
pid_kd = 800
min_temp: -30
max_temp: 110


# ─── Fans ───
[output_pin MainBoardFan]
pin: !PB1

[heater_fan nozzle_fan]
pin: !nozzle_mcu: PB3
max_power: 1.0
shutdown_speed: 0
cycle_time: 0.1
hardware_pwm: False
kick_start_time: 0.100
off_below: 0.0
heater: extruder
fan_speed: 1.0
heater_temp: 60.0

[output_pin en_nozzle_fan]
pin: nozzle_mcu: PB7
pwm: False
value: 1.0

# Front part fan
[output_pin fan0]
pin: !nozzle_mcu: PB15
pwm: True
cycle_time: 0.01
hardware_pwm: false
value: 0.00
scale: 255
shutdown_value: 0.0

[output_pin en_fan0]
pin: nozzle_mcu: PB6
pwm: False
value: 1.0

# Rear part fan
[output_pin fan1]
pin: !nozzle_mcu: PA9
pwm: True
cycle_time: 0.01
hardware_pwm: false
value: 0.00
scale: 255
shutdown_value: 0.0

[output_pin en_fan1]
pin: nozzle_mcu: PB9
pwm: False
value: 1.0


# ─── LEDs ───
[output_pin green_pin]
pin: PA0
value: 0.0

[output_pin red_pin]
pin: PC1
value: 0.0

[output_pin yellow_pin]
pin: PA1
value: 1.0

[output_pin light_pin]
pin: !PC0
value: 0.0


# ─── Bed mesh ───
[bed_mesh]
horizontal_move_z: 1
scan_overshoot: 8
speed: 100
mesh_min: 30.0, 15.0
mesh_max: 391.0, 391.0
probe_count: 15, 15
fade_start: 1.0
fade_end: 20
fade_target: 0
mesh_pps: 4, 4
algorithm: bicubic
bicubic_tension: 0.2

[exclude_object]


#*# <---------------------- SAVE_CONFIG ---------------------->
#*# DO NOT EDIT THIS BLOCK OR BELOW. The contents are auto-generated.
#*#
#*# [probe_eddy_current btt_eddy]
#*# reg_drive_current = 15
#*# calibrate =
#*# 	0.049912:3268320.848,0.089842:3266605.786,0.129772:3264973.040,
#*# 	0.169702:3263373.971,0.210256:3261773.769,0.250186:3260228.341,
#*# 	0.290116:3258616.472,0.330046:3257169.070,0.369976:3255842.890,
#*# 	0.409906:3254452.626,0.449836:3253037.242,0.489766:3251765.145,
#*# 	0.529696:3250400.970,0.570250:3249092.420,0.610180:3247713.862,
#*# 	0.650110:3246449.093,0.690040:3245293.336,0.729970:3244177.873,
#*# 	0.769900:3242892.584,0.809830:3241813.874,0.849760:3240752.410,
#*# 	0.889690:3239710.261,0.930244:3238606.281,0.970174:3237552.617,
#*# 	1.010104:3236558.962,1.050034:3235455.351,1.089964:3234505.624,
#*# 	1.129894:3233621.853,1.169824:3232639.053,1.209754:3231618.533,
#*# 	1.250308:3230748.474,1.290238:3229823.363,1.330168:3228982.326,
#*# 	1.370098:3228093.403,1.410028:3227282.149,1.449958:3226491.534,
#*# 	1.489888:3225667.423,1.529818:3224832.973,1.569748:3224073.941,
#*# 	1.610302:3223285.622,1.650232:3222497.485,1.690162:3221738.405,
#*# 	1.730092:3220913.243,1.770022:3220179.116,1.809952:3219400.098,
#*# 	1.849882:3218695.131,1.889812:3217961.118,1.929742:3217284.147,
#*# 	1.970296:3216550.738,2.010226:3215912.089,2.050156:3215216.281,
#*# 	2.090086:3214555.889,2.130016:3213895.136,2.169946:3213253.438,
#*# 	2.209876:3212642.770,2.249806:3211992.545,2.289736:3211384.263,
#*# 	2.330290:3210775.963,2.370220:3210193.312,2.410150:3209519.713,
#*# 	2.450080:3208998.170,2.490010:3208369.278,2.529940:3207799.197,
#*# 	2.569870:3207230.283,2.609800:3206664.802,2.649730:3206075.943,
#*# 	2.690284:3205587.094,2.730214:3205072.889,2.770144:3204592.127,
#*# 	2.810074:3204077.979,2.850004:3203596.433,2.889934:3203132.994,
#*# 	2.929864:3202661.509,2.969794:3202218.693,3.009724:3201778.579,
#*# 	3.050278:3201348.431,3.090208:3200900.288,3.130138:3200462.111,
#*# 	3.170068:3200048.679,3.209998:3199629.214,3.249928:3199205.081,
#*# 	3.289858:3198814.319,3.329788:3198444.175,3.369718:3198065.432,
#*# 	3.410272:3197640.599,3.450202:3197276.544,3.490132:3196890.317,
#*# 	3.530062:3196551.061,3.569992:3196189.499,3.609922:3195835.386,
#*# 	3.649852:3195467.946,3.689782:3195127.151,3.729712:3194773.815,
#*# 	3.770265:3194430.932,3.810195:3194105.487,3.850125:3193773.350,
#*# 	3.890055:3193453.324,3.929985:3193130.522,3.969915:3192830.397,
#*# 	4.009845:3192520.326,4.049775:3192236.266
#*#
#*# [temperature_probe btt_eddy]
#*# calibration_temp = 45.735728

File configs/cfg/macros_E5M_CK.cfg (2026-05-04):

# ═══════════════════════════════════════════════════════
# E5M-CK — macros_E5M_CK.cfg
# User macros: pause/park + filament load/unload + nozzle cleaning
# ═══════════════════════════════════════════════════════


[gcode_macro _PAUSE_RESUME_VARIABLES]
description: Centralized parameters for pause/resume/cancel/M600 macros
# ─── Park position ─────────────────────────────
variable_park_x          : -1.0       # X park (within position_min: -5)
variable_park_y          : 120.0      # Y park
variable_park_z_lift     : 100.0      # Z lift relative to current (capped at z_max-1)

# ─── Retract amounts ───────────────────────────
variable_retract_pause   : 5.0        # PARK_FOR_PAUSE anti-coulure retract

# ─── Speeds (mm/min) ───────────────────────────
variable_speed_park_xy   : 5000       # XY park move
variable_speed_park_z    : 600        # Z lift
variable_speed_retract   : 1800       # Retract feedrate

# ─── Cancel ────────────────────────────────────
variable_cancel_z_drop   : 380.0      # Bed Z when canceling (eject print)
variable_cancel_x        : 200.0      # X position after cancel (bed center)
variable_cancel_y        : 200.0      # Y position after cancel (bed center)

gcode:
  # No-op: this macro only holds variables for other macros to read.


[gcode_macro PARK]
description: Park toolhead at safe position (uses _PAUSE_RESUME_VARIABLES)
gcode:
    {% set v = printer["gcode_macro _PAUSE_RESUME_VARIABLES"] %}
    {% set xy_homed = 'x' in printer.toolhead.homed_axes
                       and 'y' in printer.toolhead.homed_axes %}
    {% if not xy_homed %}
        RESPOND TYPE=error MSG="PARK aborted: X or Y not homed"
    {% else %}
        # Z handling: lift if homed, else FORCE_MOVE down a bit
        {% if 'z' in printer.toolhead.homed_axes %}
            {% set z_max = printer.toolhead.axis_maximum.z|float %}
            {% set z_cur = printer.toolhead.position.z|float %}
            {% set z_target = [z_cur + v.park_z_lift, z_max - 1]|min %}
            G90
            G1 Z{z_target} F{v.speed_park_z}
        {% else %}
            FORCE_MOVE STEPPER=stepper_z DISTANCE=10 VELOCITY=5
            RESPOND TYPE=command MSG="PARK: Z not homed - bed lowered 10mm via FORCE_MOVE"
        {% endif %}

        # Move XY to park position
        G90
        G1 X{v.park_x} Y{v.park_y} F{v.speed_park_xy}

        RESPOND TYPE=command MSG="Parked at X{v.park_x} Y{v.park_y}"
    {% endif %}


[gcode_macro PARK_FOR_PAUSE]
description: Save state, retract, then park (use after PAUSE during a print)
variable_is_parked: 0
gcode:
    {% set v = printer["gcode_macro _PAUSE_RESUME_VARIABLES"] %}
    {% set is_parked = printer["gcode_macro PARK_FOR_PAUSE"].is_parked|int %}
    {% set is_paused = printer.pause_resume.is_paused %}
    {% set print_state = printer.print_stats.state %}
    {% set print_active = print_state in ['printing', 'paused'] %}

    {% if is_parked == 1 %}
        RESPOND TYPE=error MSG="PARK_FOR_PAUSE: already parked"
    {% elif print_active and not is_paused %}
        RESPOND TYPE=error MSG="PARK_FOR_PAUSE: call PAUSE first"
    {% elif is_paused %}
        # State: print in pause — save state, retract, park
        {% if printer.extruder.can_extrude %}
            SAVE_GCODE_STATE NAME=pause_state
            G91
            G1 E-{v.retract_pause} F{v.speed_retract}
            G90
            PARK
            SET_GCODE_VARIABLE MACRO=PARK_FOR_PAUSE VARIABLE=is_parked VALUE=1
            RESPOND TYPE=command MSG="Parked for pause - call RESUME to continue"
        {% else %}
            RESPOND TYPE=error MSG="PARK_FOR_PAUSE: extruder too cold for retract"
        {% endif %}
    {% else %}
        # State: idle — just park, no retract, no save
        PARK
        RESPOND TYPE=command MSG="Parked (idle, no retract)"
    {% endif %}


[gcode_macro LOAD_FILAMENT]
description: Load filament - aware of pause state for clean RESUME
gcode:
    {% set extruder_temp = params.EXTRUDER_TEMP|default(220)|int %}
    {% set extrude_len = params.EXTRUDE_LEN|default(75)|int %}
    {% set is_paused = printer.pause_resume.is_paused %}
    
    {% if is_paused %}
        # In-pause mode (e.g. after M600):
        # No SAVE/RESTORE_GCODE_STATE (preserves E counter for clean RESUME)
        # No M109/M104 (stay hot from the print)
        {% if not printer.extruder.can_extrude %}
            RESPOND TYPE=error MSG="LOAD_FILAMENT: extruder too cold"
        {% else %}
            G91
            G1 E{extrude_len} F180
            G90
            RESPOND TYPE=command MSG="Filament loaded - call RESUME to continue"
        {% endif %}
    {% else %}
        # Standalone mode (out of print): full sequence with heat + cool
        SAVE_GCODE_STATE NAME=load_filament_state
        M109 S{extruder_temp}
        G91
        G1 E{extrude_len} F180
        M104 S0
        RESTORE_GCODE_STATE NAME=load_filament_state
    {% endif %}


[gcode_macro UNLOAD_FILAMENT]
description: Unload filament (heat, anti-ringing retract sequence, cool down)
gcode:
    {% set extruder_temp = params.EXTRUDER_TEMP|default(220)|int %}
    SAVE_GCODE_STATE NAME=unload_filament_state
    M109 S{extruder_temp}
    G91
    G1 E100 F300
    G1 E-15 F3000
    G1 E-22.4700 F2400
    G1 E-6.4200 F1200
    G1 E-3.2100 F720
    G1 E5.0000 F356
    G1 E-5.0000 F384
    G1 E5.0000 F412
    G1 E-5.0000 F440
    G1 E5.0000 F467
    G1 E-5.0000 F495
    G1 E5.0000 F523
    G1 E-5.0000 F3000
    G1 E-15 F3000
    M104 S0
    RESTORE_GCODE_STATE NAME=unload_filament_state


# ─── NOZZLE CLEANING ON SILICONE BRUSH ─────────────────
# Multi-phase nozzle cleaning routine designed to leave the nozzle
# at a stable 140°C ready for SET_SCAN_FROM_TAP (tap-then-scan).
#
# Phase 1: approach the brush, heat to 180°C, run 5 zigzag passes
# Phase 2: active cooldown 180→140°C with fans full + 12 zigzag passes
# Phase 3: wait for stable 140°C, turn fans off
# Phase 4: 5 final cold brushes at 140°C
# End:     park at Z20 X0 Y50 and turn off the heater
#
# Called from the print start G-code (start_gcode_ORCA_E5M-CK.txt).
# Brush is mounted at X=-3..-2 (left of bed), Y=50..80.
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

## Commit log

2026-04-28 My E5M CK presets
    Use with care. I offer no warranty.
    - K2 Plus nozzle mod
2026-04-30 Rename 0.16mm HIGH Quality for 0.4 K2 Plus Nozzle @E5M-CK thx to BICIO_TOP.json to assets/orca configs/0.16mm HIGH Quality for 0.4 K2 Plus Nozzle @E5M-CK thx to BICIO_TOP.json
2026-04-30 Rename Toolhead E5M-CK.3mf to assets/prints/Toolhead E5M-CK.3mf
    [Toolhead E5M-CK.3mf]
2026-05-05 Update and rename probe_eddy_auto_calibrate.py to Eddy E5M CK beta/probe_eddy_auto_calibrate.py
2026-05-05 Rename probe_eddy_auto_calibrate.py to Eddy E5M CK beta/probe_eddy_auto_calibrate.py
2026-05-06 Create save-config printer cgf 060526 1352
